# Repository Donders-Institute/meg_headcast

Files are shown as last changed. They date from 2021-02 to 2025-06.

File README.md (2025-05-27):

# Making and using MEG headcasts

Precisely fitting headcasts that fill the gap between the participant's head and the inside of the MEG dewar can ensure that a subject is positioned in the MEG such that he/she cannot move in long experiments, and that the subject can be repositioned in exactly the same way in subsequent sessions. Making a headcast takes time and money.

Relevant literature and links:

- Meyer, Barnes et al. Flexible head-casts for high spatial precision MEG. J Neurosci Methods, 2017. Jan 30;276:38-45. doi: 10.1016/j.jneumeth.2016.11.009
- Chella, Barnes, Pizzella et al. The impact of improved MEG-MRI co-registration on MEG connectivity analysis. Neuroimage. 2019 Aug 15;197:354-367. doi: 10.1016/j.neuroimage.2019.04.061

People with (varying levels of) experience at the DCCN:

- Tom Marshall (currently at Oxford)
- Kristijan Armeni (currently at Johns Hopkins)
- Jan-Mathijs Schoffelen
- Bob Bramson
- Felix Klaassen

## Designing the headcasts

This repository contains code, 3D models, and documentation that was compiled over the years at the Donders Centre for Cognitive Neuroimaging (DCCN) at the Donders Institute, Radboud University Nijmegen, NL.

The [design_v1](design_v1) directory represents the procedure as designed by Robert in 2021. It has been superseded by the [design_v2](design_v2) procedure following the pilots of Bob and Uriel. Please ask Miranda or Jan-Mathijs for up-to-date details.

## 3D printing the head and pouring the foam

In the most recent procedure for pouring the foam we use a 3D printed mold of the dewar that can be disassembled into different pieces. The 3D printed head can be attached to this mold with screws to keep it fixated during the pouring process. The inside of the mold and the outside of the head need to be pre-treated with wax to prevent the foam from sticking too much.

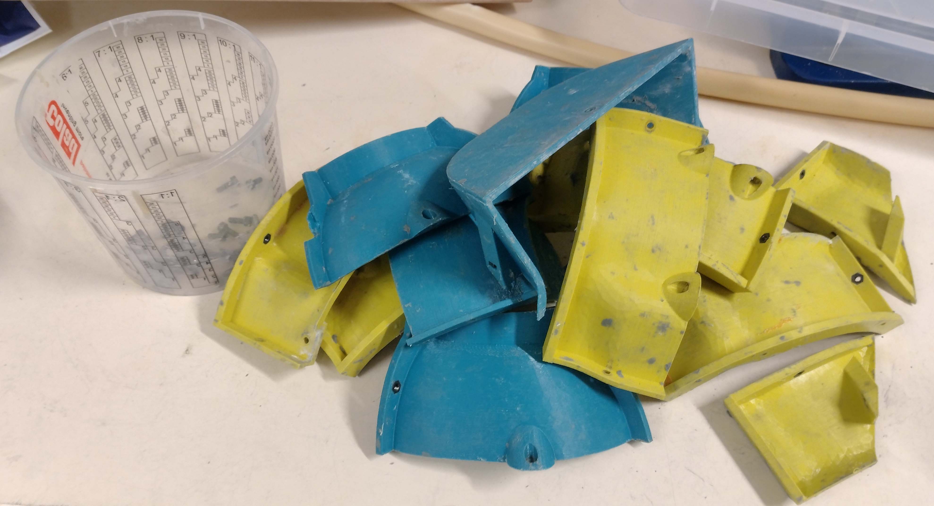
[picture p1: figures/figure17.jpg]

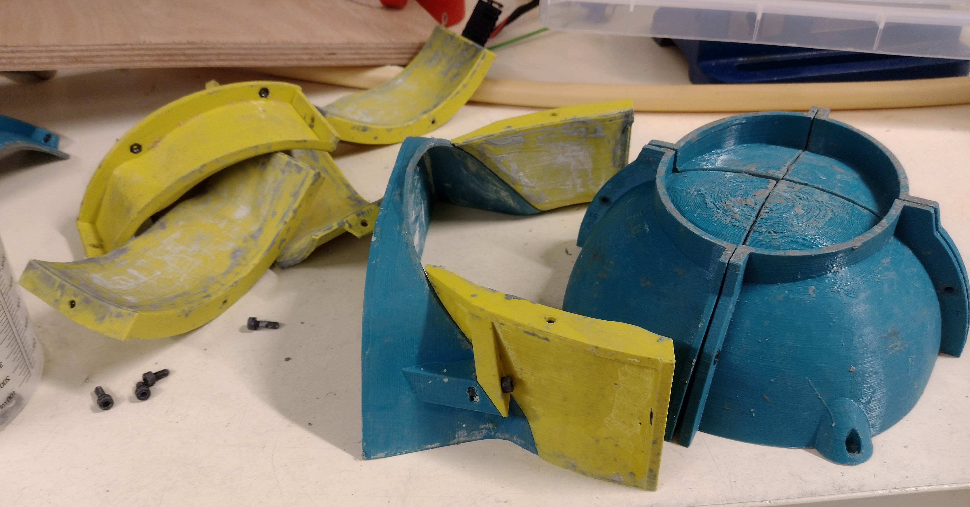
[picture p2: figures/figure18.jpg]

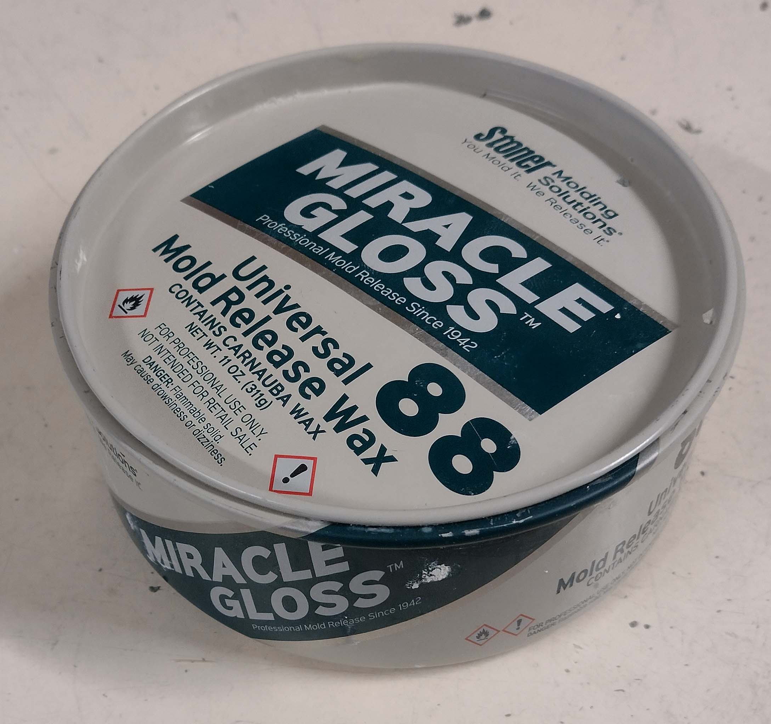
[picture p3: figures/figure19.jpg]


## Safety precautions

We should take extra care with the participants' safety when performing MEG experiments with the headcast in place. Since the participants may be highly immobilized, once positioned, it is very important **NOT** to move the chair! Or to quote Gareth: _"Our primary safety measure is therefore to ensure that neither the chair nor the dewar is moved while the subject is wearing a head-cast"_.

See also <https://www.youtube.com/watch?v=tVozndvAgyw+>

For researchers within the DCCN, please consult the standard operating procedure (SOP), which is included in this repository for reference. When using headcasts in the MEG lab of the DCCN, **always check for the latest version** of the SOP on the [DCCN intranet](https://intranet.donders.ru.nl/index.php?id=meg-lab-procedures).

- [standard operating procedure (DCCN)](labinstructions_dccn/SOP_headcast_20220818.pdf)

Researchers from outside the DCCN might also be interested in the lab procedures that are in use in the MEG lab at the UCL, which Gareth Barnes was so kind to share:

- [standard operating procedure (UCL)](labinstructions_ucl/WTCN_MEG_HEADCAST_SOP_march2015.pdf)
- [emergency procedure](labinstructions_ucl/WTCN_MEG_HEADCAST_Emerg_proc_Appendix2.pdf)
- [training checklist](labinstructions_ucl/WTCN_MEG_HEADCAST_training_Appendix1.pdf)
- [volunteer guide](labinstructions_ucl/volunteerguide_v2.pdf)

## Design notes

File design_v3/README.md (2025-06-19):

# Designing a MEG headcast - iteration 3

This is the 3rd iteration of the process to design and construct individualized headcasts for the CTF MEG system.

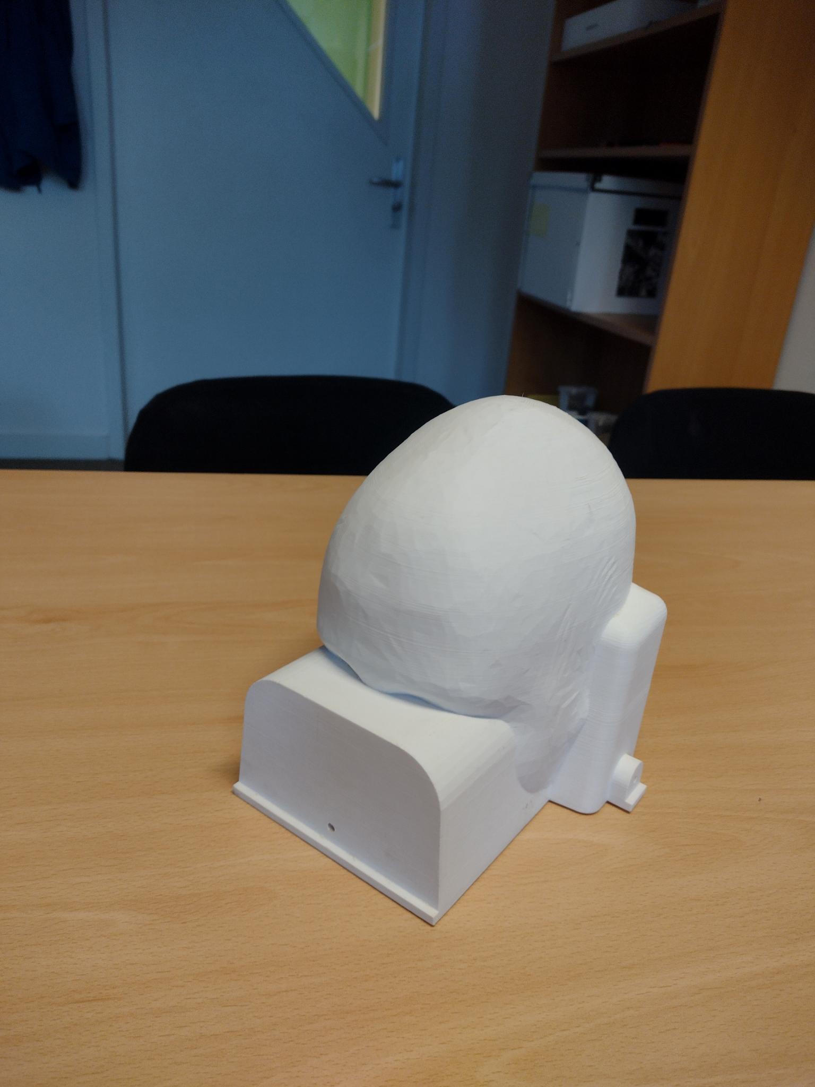
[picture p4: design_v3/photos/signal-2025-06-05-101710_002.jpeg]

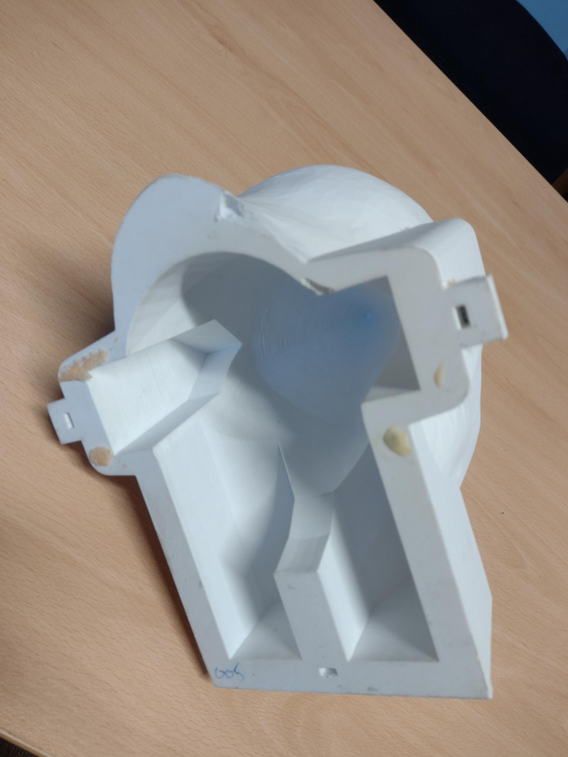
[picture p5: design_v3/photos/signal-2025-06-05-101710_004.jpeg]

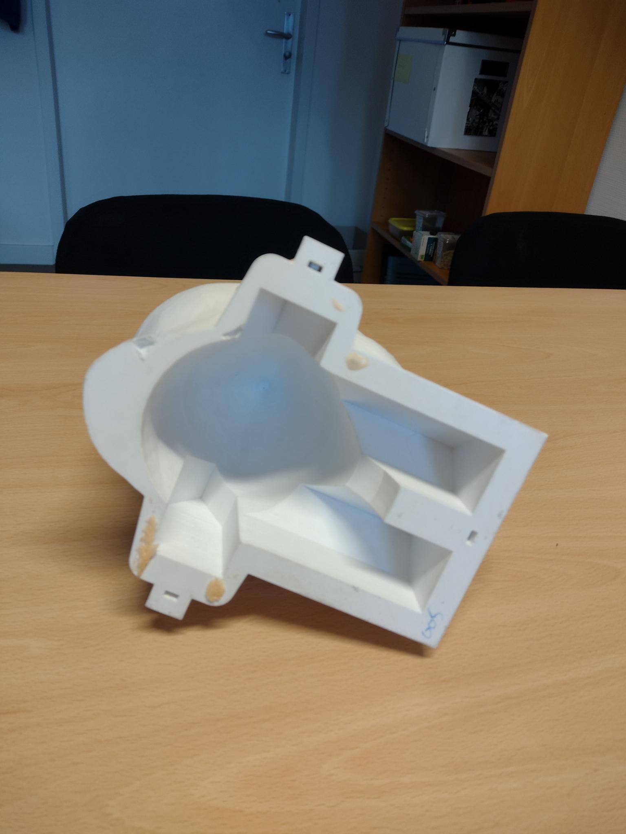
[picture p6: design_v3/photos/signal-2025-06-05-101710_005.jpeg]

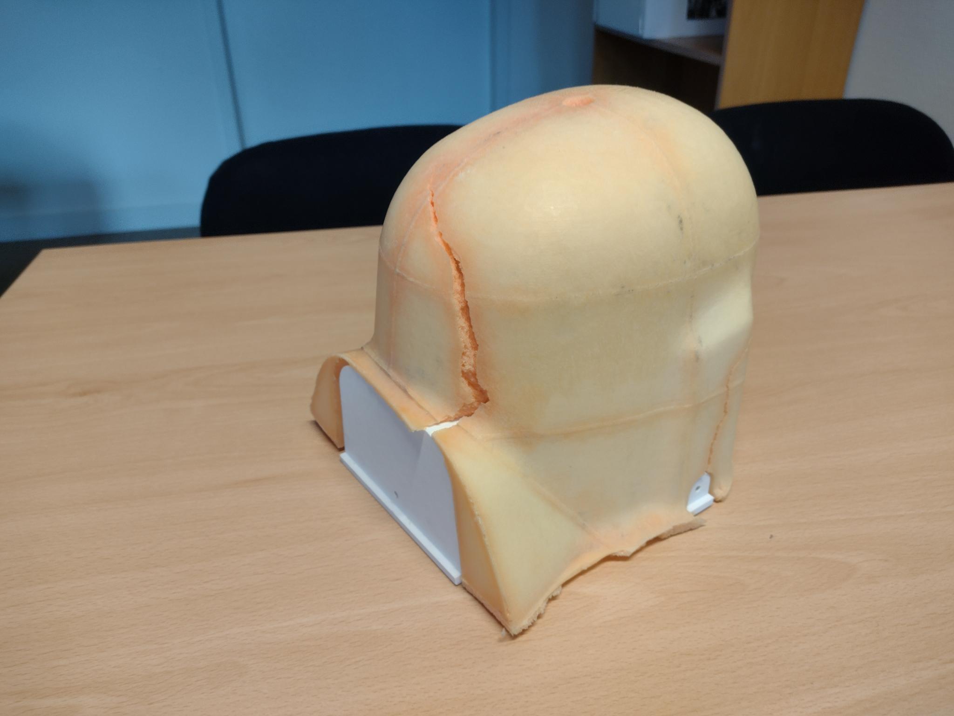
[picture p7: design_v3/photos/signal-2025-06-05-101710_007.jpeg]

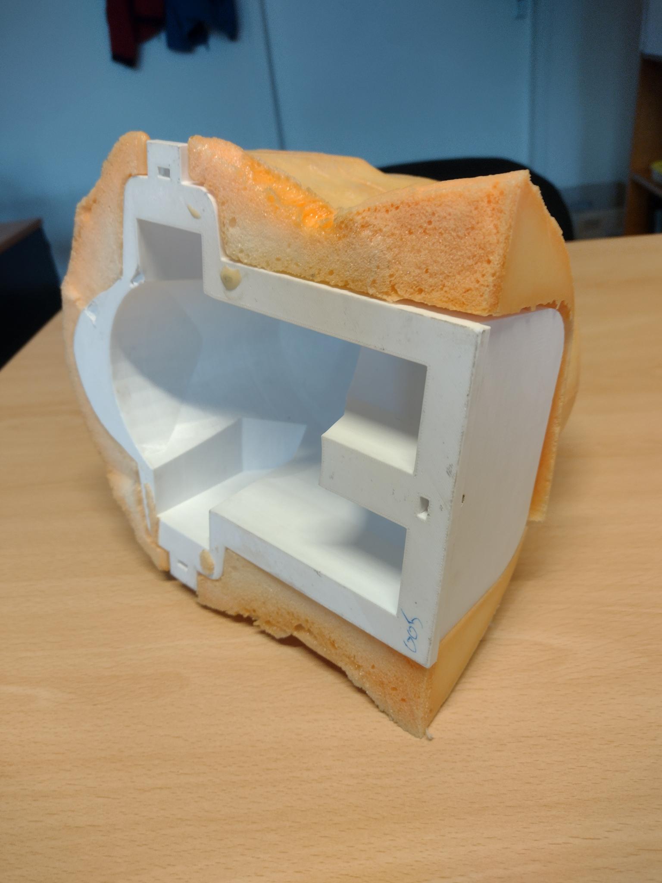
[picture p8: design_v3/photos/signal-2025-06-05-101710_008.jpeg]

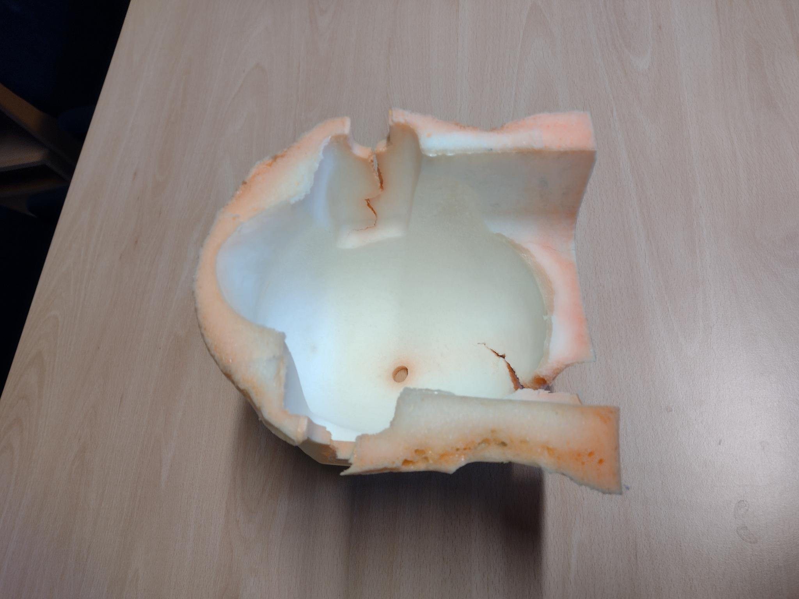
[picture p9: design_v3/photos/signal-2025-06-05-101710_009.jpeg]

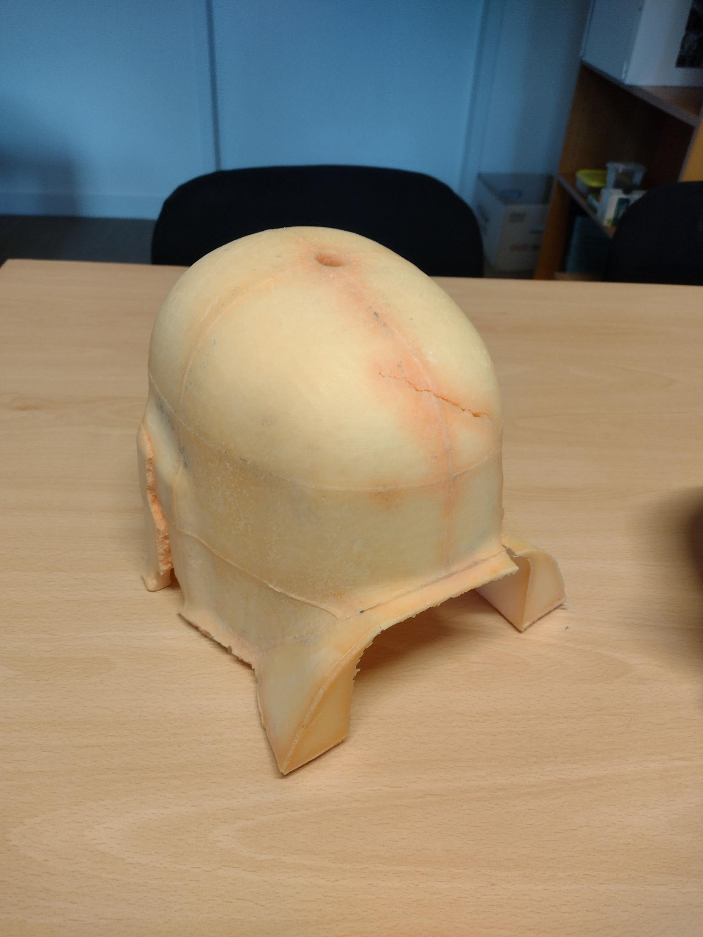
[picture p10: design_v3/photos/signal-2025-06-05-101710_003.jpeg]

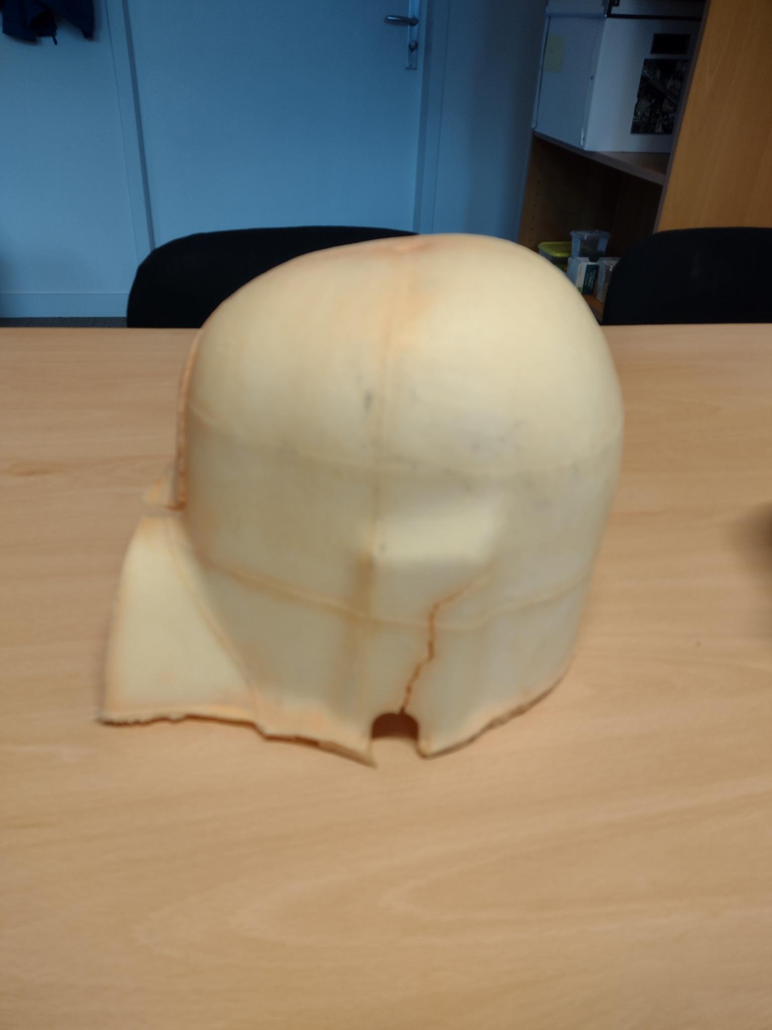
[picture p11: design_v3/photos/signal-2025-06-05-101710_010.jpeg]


We start by making a computer model of the head surface that is aligned properly with the MEG helmet (which is also called the dewar).

First follow the [procedure](./procedure.m) in MATLAB using FieldTrip:

- importing the MRI (as DICOM or NIFTI)
- segmenting the head surface with ft_volumesegment
- positioning the head surface in the dewar using ft_interactiverealign
- exporting the aligned head surface

Then in MeshLab, as explained in this [YouTube video](https://www.youtube.com/watch?v=7c7nLuYW4Ns):

- read in the headshape, neckslab, noseslab, headcore and moldcore STL files.
- subtract the noseslab from the headshape, this removes the tip of the nose (not always needed, but it cannot hurt)
- subtract the neckslab from the headshape, this removes everything below the dewar
- combine the headshape and headcore
- subtract the moldcore from the combined headshape+headcore
- export the resulting mesh as the final STL file to be printed

Printing can be done on any 3D printer with a sufficiently large build volume, but our experience so far has been with a Prusa i3 Mk3 printer and the following settings:

- 0.20 layer height, speed
- Devil Design PETG
- Fill 15%
- No support (*)
- The infill pattern can be 'adaptive cubic' to save, but a regular pattern is also fine.
- 2 or 3 perimeters. More perimeters makes the print stronger, but also increases print time.

(*) If support is needed in the back of the neck, it is recommended  to use organic ssupport, at least if it fits on the base plate. Otherwise, regular support blocks can be used to limit support only to the desired area's.

Pouring of the foam between the 3D printed head model and the piecewise 3D printed model of the dewar is done using the existing procedure, where both the head model and the inside of the dewar model need to be treated with wax to prevent them from sticking to the foam.

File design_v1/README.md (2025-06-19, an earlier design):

# Designing a MEG headcast - iteration 1

This procedure is designed to use [MATLAB](https://nl.mathworks.com/products/matlab.html) and [MeshMixer](https://www.research.autodesk.com/projects/meshmixer/), which is a free software package for 3D design. [MeshLab](https://www.meshlab.net) is another free and useful tool for reviewing and editing STL meshes.

## Summary

The procedure for designing the initial 3D model of the scalp surface and aligning it
with the coordinate system and the head localizer coils is implemented in `do_make_headcast.m`.

To set up the MATLAB path, you can use `do_startup.m`.

The 3D model of the scalp surface is exported to MeshMixer, together with the dewar and a
number of auxiliary shapes (coils, binoculars, earflaps). In MeshMixer these are put together
and the dewar is "subtracted from the scalp model. The resulting model can be 3D printed.

The 3D printed "positive" model is placed in the dewar. Polyurethane foam resin is poured between
the model and the dewar to fill the gap, thereby creating the "negative" head cast.

The `prepare_xxx.m` files are only included for reference, these were used to create
the `.mat` models that are included here.

## Procedure

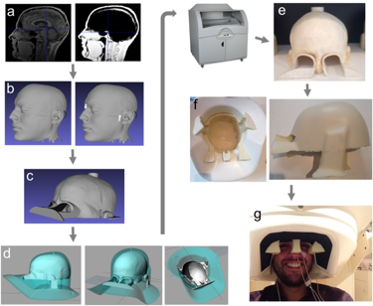
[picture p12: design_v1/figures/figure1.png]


The procedure that is described here can be outlined as follows:

- a) Head surface is extracted from an anatomical MRI image using the standard SPM12 segmentation procedure.
- b) Head surface extraction is converted to a surface file and fiducial coils are added. The coil locations are defined in MRI coordinates.
- c) A positioning cylinder at the top of the head is added to the virtual model to define the position of the head inside the head-cast. Eye extensions are added to enable vision during use.
- d) Using and adjusting the positioning cylinder, eye extensions and ear extensions, the virtual head model is positioned appropriately inside a virtual copy of the MEG dewar.
- e) The positive head model is 3D printed.
- f) The 3D print is placed inside the manufacturer-provided dewar copy (as in d) and foam resin is poured in to fill the gap between the printed positive head model and the dewar. The fiducial coil protrusions on the 3D printed head result in coil-shaped and coil-sized indentations in the head-cast (the nasion coil protrusion is visible between the eyes in e).
- g) The subject can now wear the flexible foam head-cast and enter into the (real) MEG dewar for scanning.

## Making the anatomical MRI

A specific MRI sequence is needed to minimize the distortion at the interface between skin and air. Jan-Mathijs figured out the details with Jose. Our scanners have a sequence according to the FIL specifications, and a better one (according to Jose). Jan-Mathijs compared them with Kris, and they don't appear to differ significantly. In Kris' experiments they used the FIL sequence.

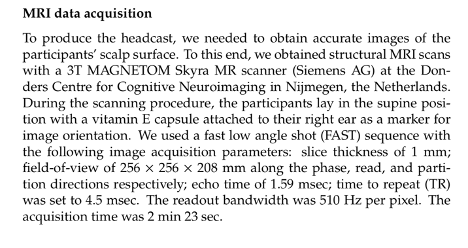
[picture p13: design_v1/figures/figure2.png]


Complete coverage is important, even more so that with a normal anatomical MRI for MEG purposes.

Hair is not visible on the MRI. The ears in the segmented MRI might be too flat to the head, hence the ears need some additional space in the model.

## Creating the 3D model element

The initial MATLAB code from Jan-Mathijs was shared with Bob. I started with the code of Jan-Mathijs, and especially improved on the coregistration and modeling the cut-outs for eyes and ears.

The first phase is implemented in MATLAB and consists of

- importing the DICOM images
- doing a coarse alignment of the MRI to the CTF coordinate system
- segment the head surface
- construct the head surface

The second phase is implemented in MATLAB and consists of

- load the geometrical model of the axes (+x, +y , -y)
- shift the head surface so that it is nicely aligned relative to the axes
- apply the transformation from step 6 also to the anatomical MRI
- export the aligned head surface

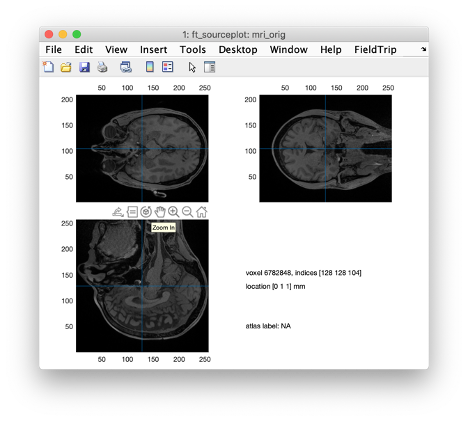
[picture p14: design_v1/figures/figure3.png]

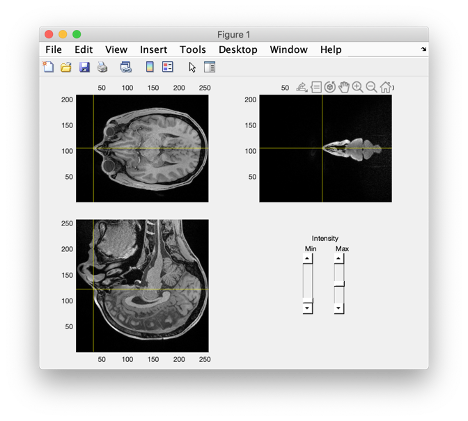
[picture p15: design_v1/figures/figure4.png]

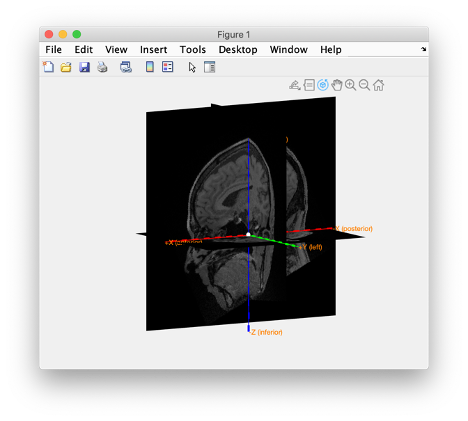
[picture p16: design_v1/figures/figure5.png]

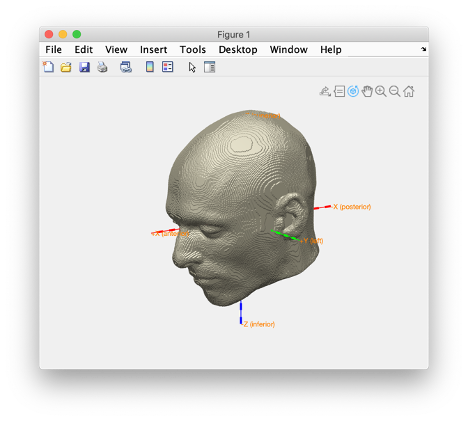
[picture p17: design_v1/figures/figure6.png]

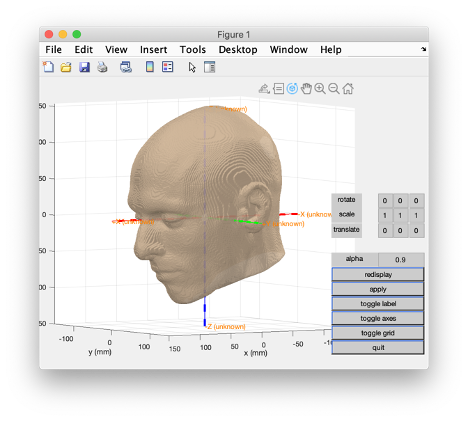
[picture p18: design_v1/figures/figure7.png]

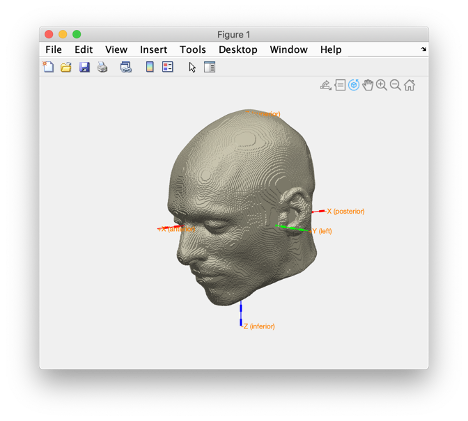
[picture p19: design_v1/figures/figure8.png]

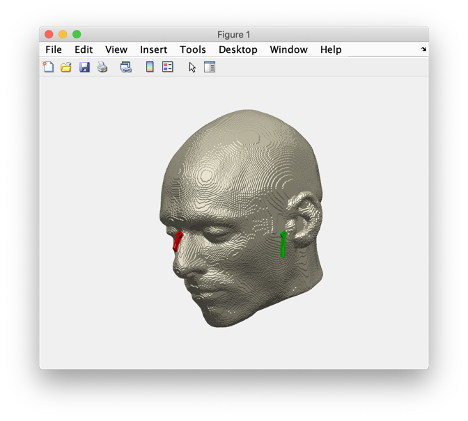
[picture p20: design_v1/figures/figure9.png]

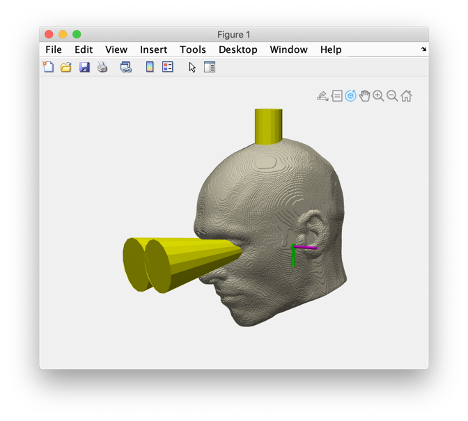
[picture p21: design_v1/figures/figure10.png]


This process results in

- dewar.stl
- earcanal_left.stl
- earcanal_right.stl
- earflap_left.stl
- earflap_right.stl

Which all need to be aligned to the following

- scalp_coreg3.stl
- combined_axes.stl
- headcoil_lpa_coreg3.stl
- headcoil_nas_coreg3.stl
- headcoil_rpa_coreg3.stl
- binoculars.stl
- vertex_cylinder.stl

The scalp and head coils are all aligned to the axes and should not be moved relative to each other, but - if needed - the binoculars and vertex cylinder can be moved for a better fit.

## Positioning the head relative to the helmet (or vice versa)

1. Load all model components in MeshMixer.
2. Check the alignment of the scalp and head coils relative to combined axes, then discard the axes.
3. Hide the ear flaps and canals from view.
4. Move the dewar to the desired position relative to the head.
5. Move the ear flaps to the right position, keep them together (i.e. select them both) when you rotate and translate them, only start moving them separately when you move in and out to have them intersect at the right depth with the head.
6. When you move the ear flaps (together, or separate on left and right), you should keep the ear canals selected as well: you want their surfaces to stay aligned. Only when the flaps are in place, you select the left and right canal and rotate/translate them so that the ear canal spans the whole ear to the top.
7. Optionally: move the binoculars and vertex cylinder.
8. Save the intermediate model to a .mix file.
9. Select the binoculars and cut it with a plane, removing the front of the binoculars. Add a cube, and scale/translate/rotate that so that it forms a slab or a plate to close the front of the dewar. This should prevent the resin from pouring out.
10. Combine the scalp, head coils, ear flaps, ear canals, and front plate in one object. Make that object solid.
11. Select the solid combined model and cut it with a plane, removing everything that sticks out underneath the dewar.
12. Select the dewar and make it solid. Make a copy of it, you will need it later.
13. Select the solid model and the solid dewar, then do boolean difference. Use intersection curves.
14. Select the solid model and do separate shells. This will convert it into multiple objects. Keep the large part that is inside the dewar and delete all other small marts (e.g. the top part of the cylinder that sticks out, and the outer parts of the ear flaps).
15. Save the final model to another .mix file.
16. Export the solid model to an STL file, note: do not press Ctrl-S but do “save as” to prevent overwriting the intermediate model, you may want to return to that model.
17. Optionally export the copy of the solid dewar, this will help in later visualisation

Tilt the neck so that the subject is in a comfortable position. At this moment it is also important to think of the position of the head in the dewar; some studies might have more interest in the frontal parts of the brain, or in the occipital parts, and hence might want to try to get those specifically closer to the helmet.

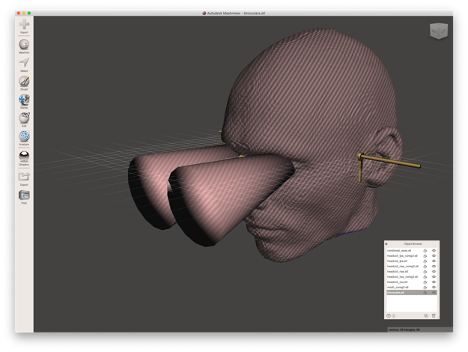
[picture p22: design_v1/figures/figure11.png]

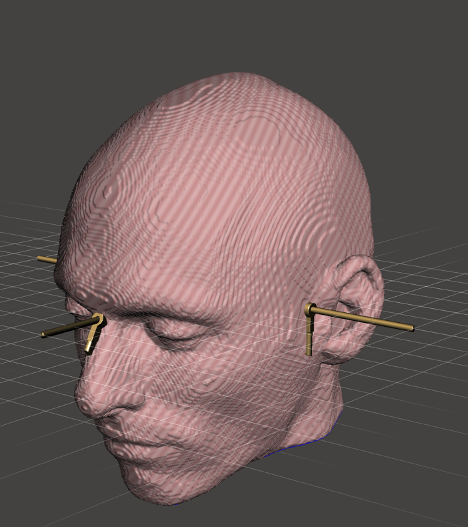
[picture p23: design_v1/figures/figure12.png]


The third phase is implemented in MeshMixer and consists of

- load the geometrical model of the aligned head surface
- load the geometrical model of the axes (+x, +y , -y)
- load the geometrical model of the LPA, RPA and NAS head localizer coils
- move the head localizer coils along the axes to the scalp surface
- load the geometrical model of the "binoculars"
- if needed move the binoculars to match the subjects eye position and gaze direction
- load the geometrical model of the vertex cylinder
- if needed move the vertex cylinder
- remove the geometrical model of the axes
- merge the head surface, coils, cylinder and binoculars in a single surface
- load the model of the dewar
- move the dewar so that the head is properly positioned, paying attention to the gaze direction
- crop the aggregate head model to remove everything that is outside the dewar
- crop the aggregate head model to remove the neck and lower head

The fourth phase is implemented in MeshMixer and consists of

- make the aggregate head model hollow
- export the aggregate head model to an STL file to get it printed

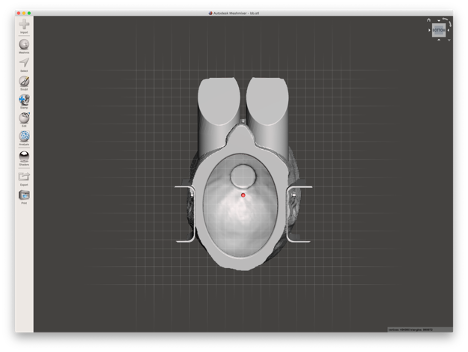
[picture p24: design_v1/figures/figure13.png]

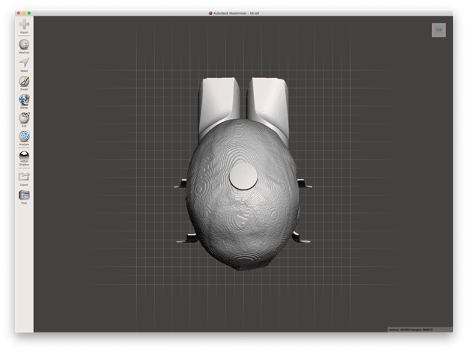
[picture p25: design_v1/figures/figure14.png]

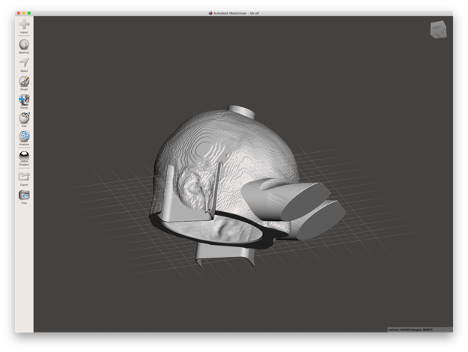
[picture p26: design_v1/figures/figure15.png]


After the 3D model has been written to STL format, it can be sliced and printed. Printing can done with FDM (Fused Deposition Modeling) using a filament, or using SLS with a powder and a laser.

The first model I finished fits on the print bed of a Prusa i3 mk2s printer, see screenshot. Estimated printing time is approximately 69 hours, requires appropriately 250 meter filament (including all supports), which costs about 15 euro.

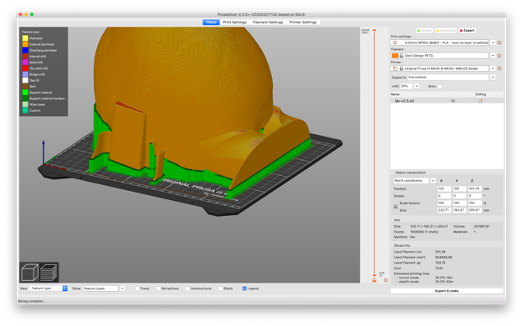
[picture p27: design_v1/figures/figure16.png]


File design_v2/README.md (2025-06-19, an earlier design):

# Coregistering a MEG headcast - iteration 2

The code and models in this folder have been written with the purpose of doing coregistration, not
so much for creating the model that is is to be 3D printed.

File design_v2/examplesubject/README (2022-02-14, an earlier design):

This directory contains for pil-002 the anatomical image that
was used to create a few headshape_*.stl files. From one of those
headshapes, the pil-002_*.stl files were derived. The latter files
reflect the location of the head localizer coils on the printed
headsurface, as well as the placement of the headsurface in the dewar
helmet. In combination with the *.ds dataset, which was obtained with the
headcast in place, it should be possible to obtain a mapping between the
sensors and the dewar helmet surface. 

The *.ds dataset is a mvDs result of the original 01_Headlocalization_20220211_01.ds
dataset, that is in the catch all collection. The identity of pil-002 is
Jan-Mathijs Schoffelen. 

CONTEXT:

Based on interactions with the CTF-engineers, it's likely that the
inaccuracy of the alignment between sensors and dewar helmet is not to be
neglected. In other words, alignment of headcast with the MEG based on
geometrical information might not be sufficiently accurate. Geometry based
alignment is assumed to be possible in the context of headcasts that do not 
explicitly include spare room for the head localization coils. The first
generation headcasts created in London (e.g. pil-002) include the coils.
The headcasts created with the DCCN protocol do not include the coils.
This makes the latter amenable to coregistration inaccuracies introduced
by the researcher (e.g. in the Polhemus procedure, or by coregistering
the anatomical image). On the other hand, placing the coils on the
subject directly, rather than in the cast, gives a more accurate account
of the residual movement during the MEG measurement.

The engineers at CTF claim the head localizer coil base coregistration
might be more accurate than the geometrical details they have provided
about the sensors-in-dewar configuration. The idea would be that pil-002 
is to be used as a 'benchmark' subject to do a head localizer based
coregistration. As long as the system geometry is stable i.e. in between
maintenance sessions during the which the sensors are taken out, it is
probably the best estimate that can be made.

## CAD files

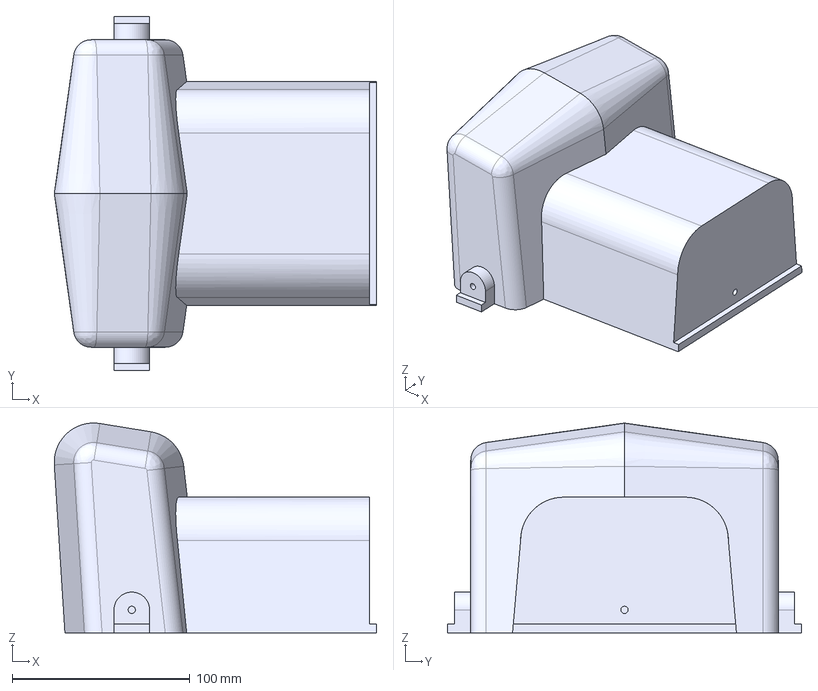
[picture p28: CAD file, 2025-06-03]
design_v3/models/step/headcore.step
181.4 x 199.1 x 118.1 mm

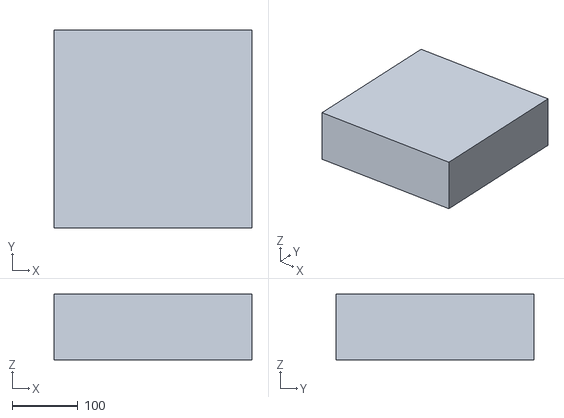
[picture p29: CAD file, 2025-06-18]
design_v3/models/stl/neckslab.stl
300.0 x 300.0 x 100.0

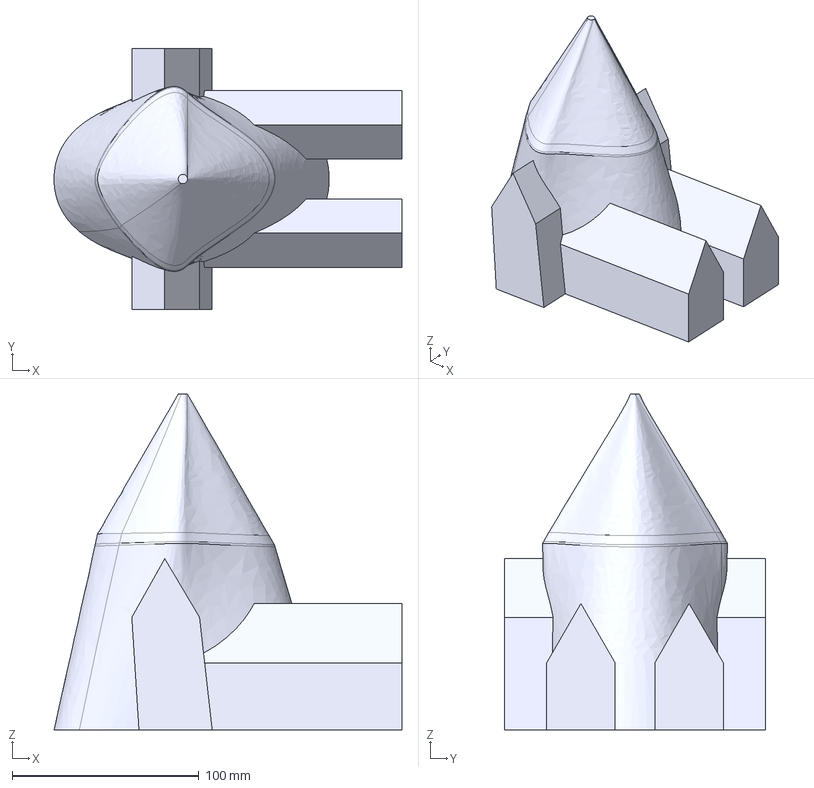
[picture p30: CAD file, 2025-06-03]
design_v3/models/step/moldcore.step
186.6 x 140.0 x 180.0 mm

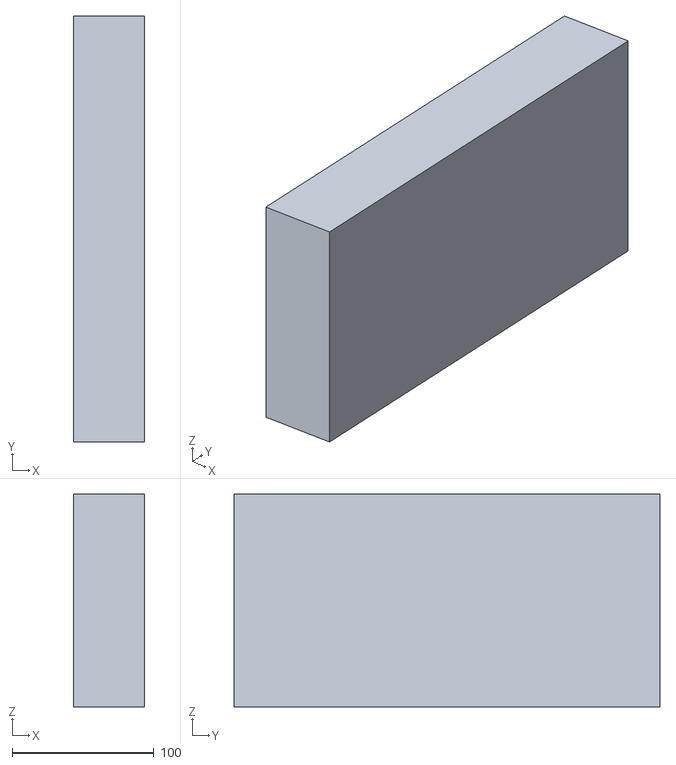
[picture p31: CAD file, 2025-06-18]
design_v3/models/stl/noseslab.stl
50.0 x 300.0 x 150.0

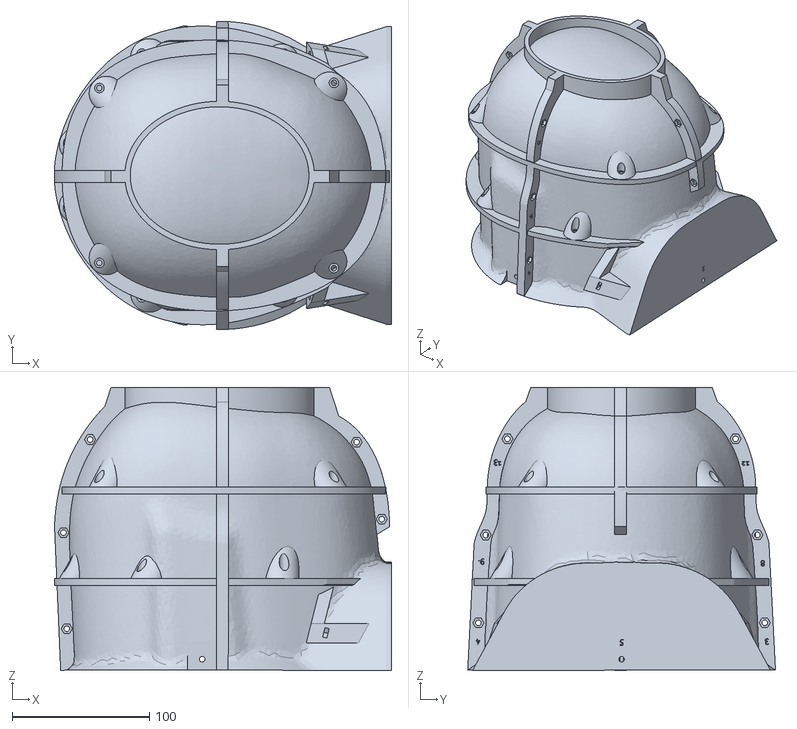
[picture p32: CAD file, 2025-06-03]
design_v3/models/stl/dewar.stl
245.3 x 224.2 x 206.0

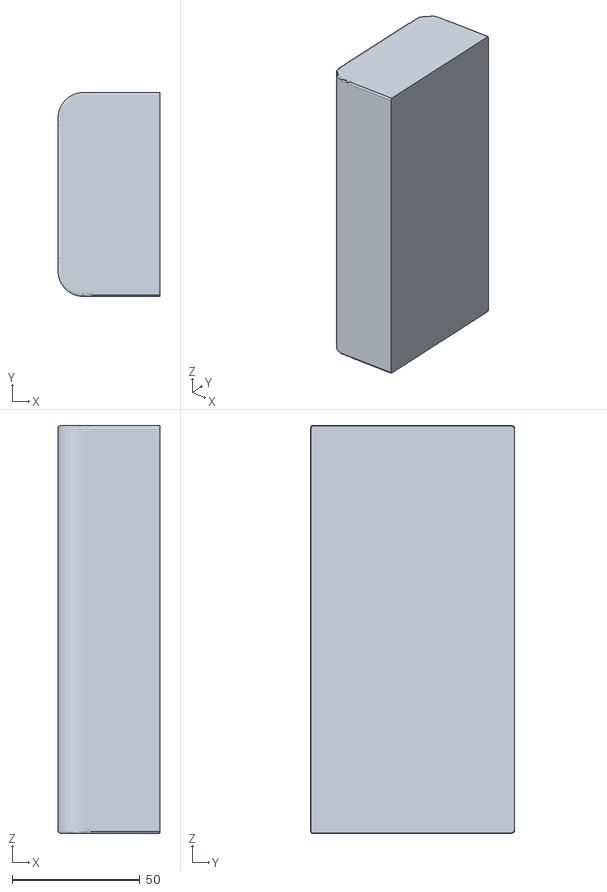
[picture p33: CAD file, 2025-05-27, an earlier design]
design_v1/models/stl/earflap_solid.stl
40.0 x 80.0 x 160.0

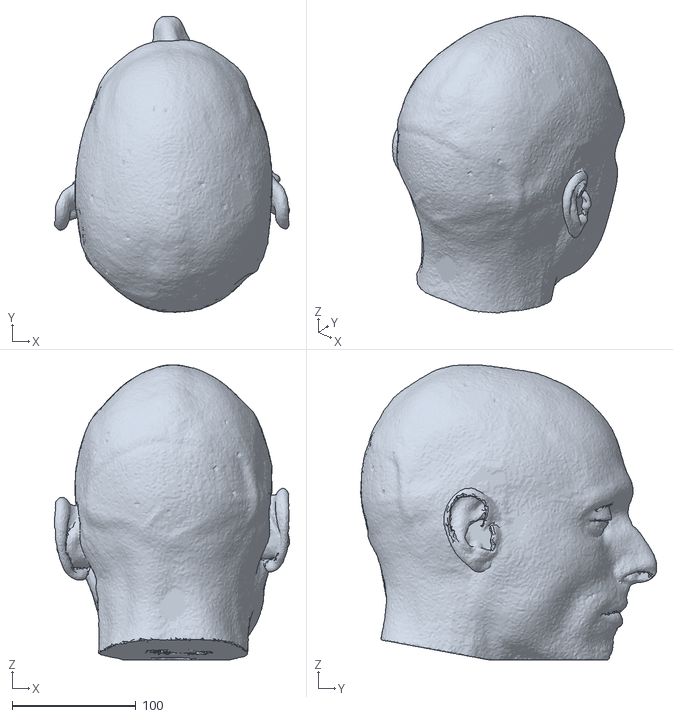
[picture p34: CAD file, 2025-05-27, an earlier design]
design_v2/examplesubject/headshape_iso2mesh_ups.stl
190.0 x 239.5 x 238.5

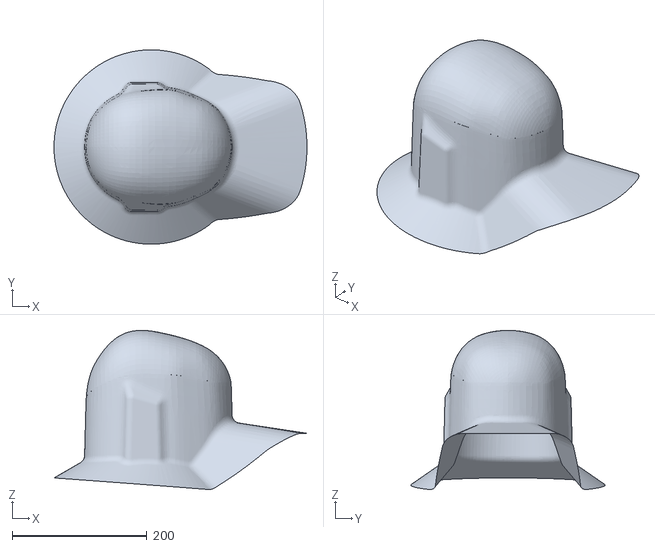
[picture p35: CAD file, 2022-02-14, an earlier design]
design_v2/models/stl/dewar_ctf.stl
375.2 x 288.2 x 236.2

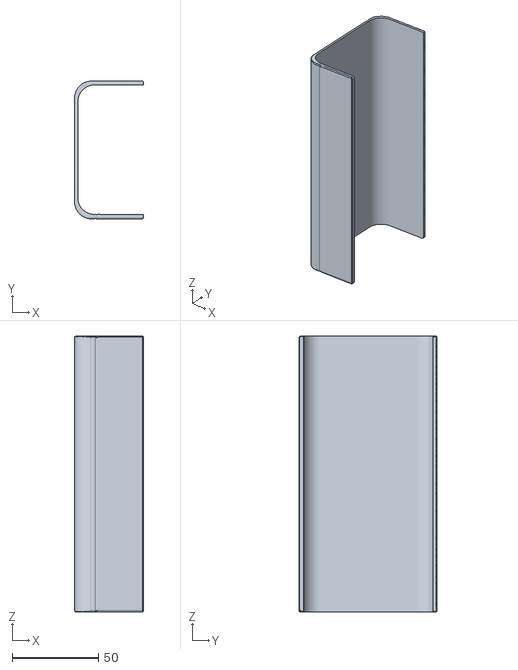
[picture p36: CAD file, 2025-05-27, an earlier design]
design_v1/models/stl/earflap_hollow.stl
40.0 x 80.0 x 160.0

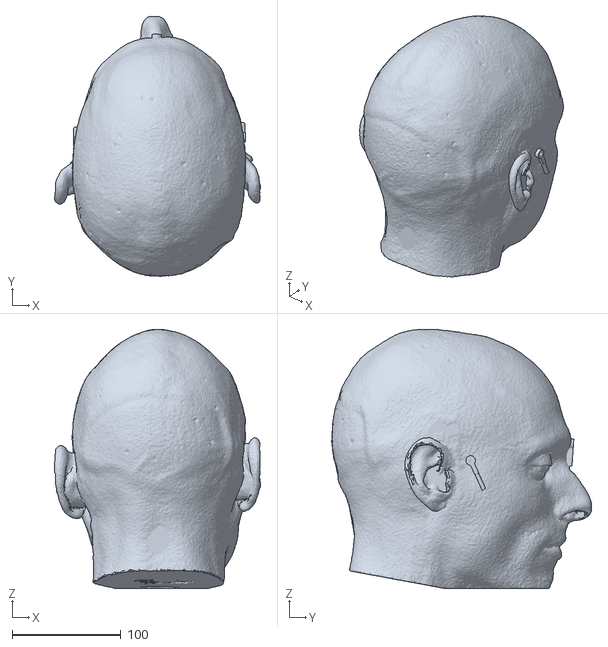
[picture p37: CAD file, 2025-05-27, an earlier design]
design_v2/examplesubject/pil-002_fiducials.stl
190.0 x 239.5 x 238.5

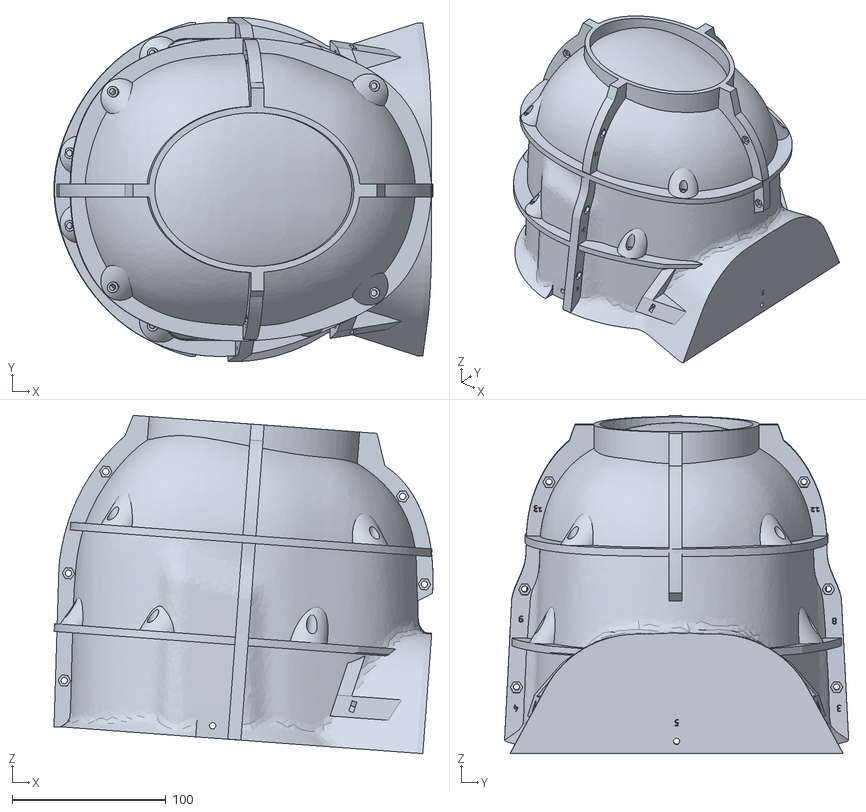
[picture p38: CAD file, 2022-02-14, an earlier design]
design_v2/models/stl/dewar_mold.stl
246.8 x 224.2 x 220.3

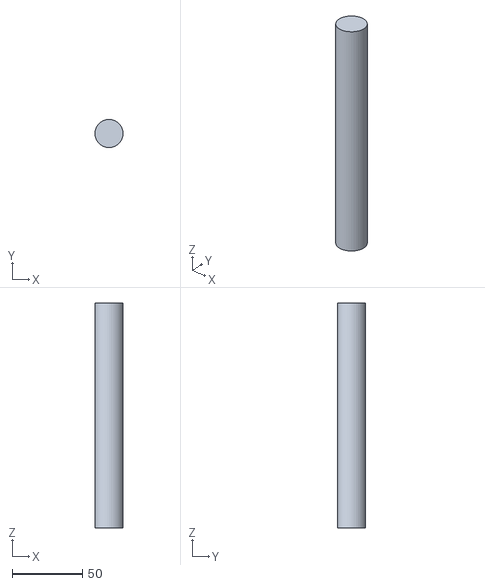
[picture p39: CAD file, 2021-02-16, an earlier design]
design_v1/models/stl/earflap_part1.stl
20.0 x 20.0 x 160.0

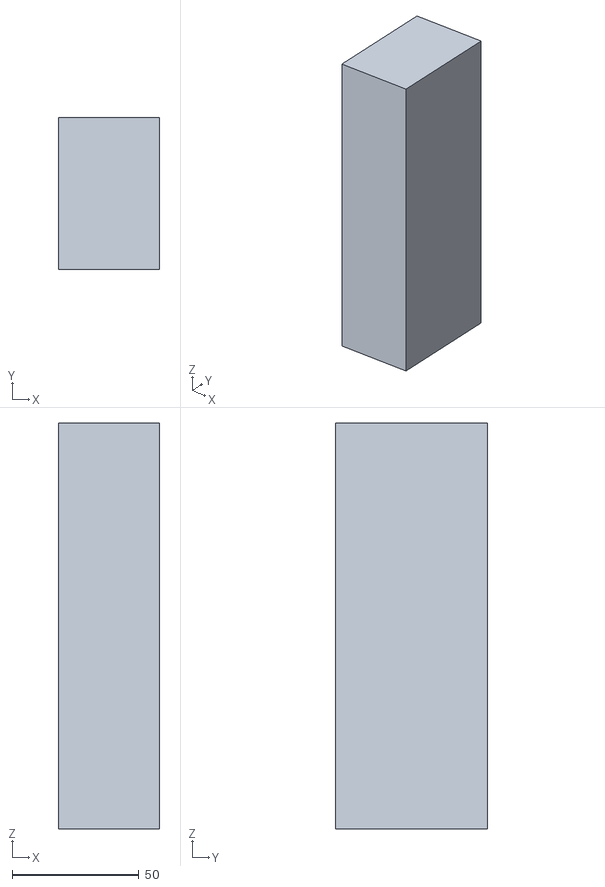
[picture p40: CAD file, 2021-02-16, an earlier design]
design_v1/models/stl/earflap_part3.stl
40.0 x 60.0 x 160.0

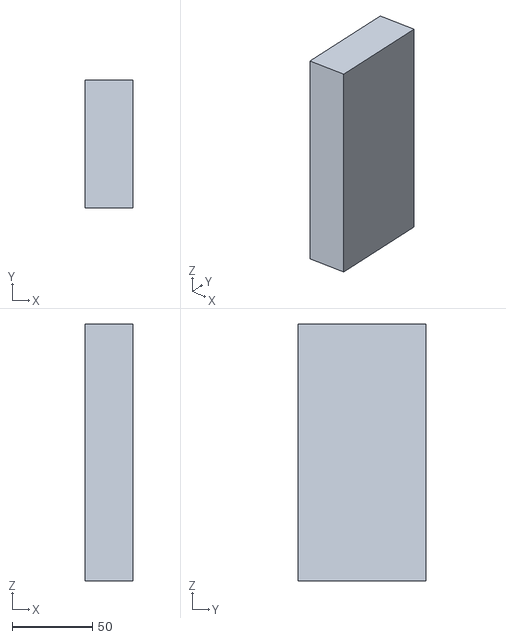
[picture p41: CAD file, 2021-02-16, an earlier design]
design_v1/models/stl/earflap_part4.stl
30.0 x 80.0 x 160.0

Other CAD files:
design_v2/examplesubject/headshape_iso2mesh.stl
design_v1/models/stl/earflap_part2.stl
design_v1/models/stl/headcoil_lpa.stl
design_v1/models/stl/headcoil_nas.stl
design_v1/models/stl/headcoil_rpa.stl
design_v3/models/stl/headcore.stl
design_v3/models/stl/moldcore.stl

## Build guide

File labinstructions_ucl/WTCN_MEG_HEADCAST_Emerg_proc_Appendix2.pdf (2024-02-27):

Appendix II: Head-cast emergency procedures

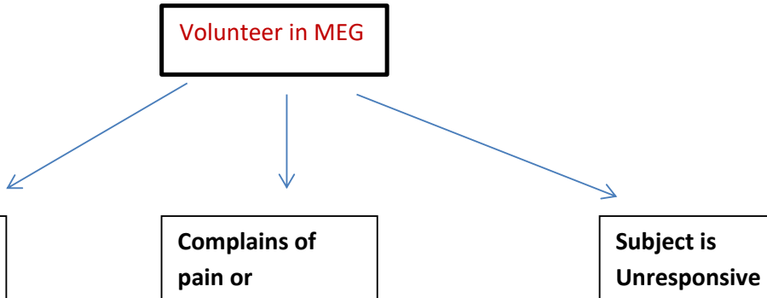
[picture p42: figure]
Volunteer in MEG; Complains of pain or; Subject is Unresponsive
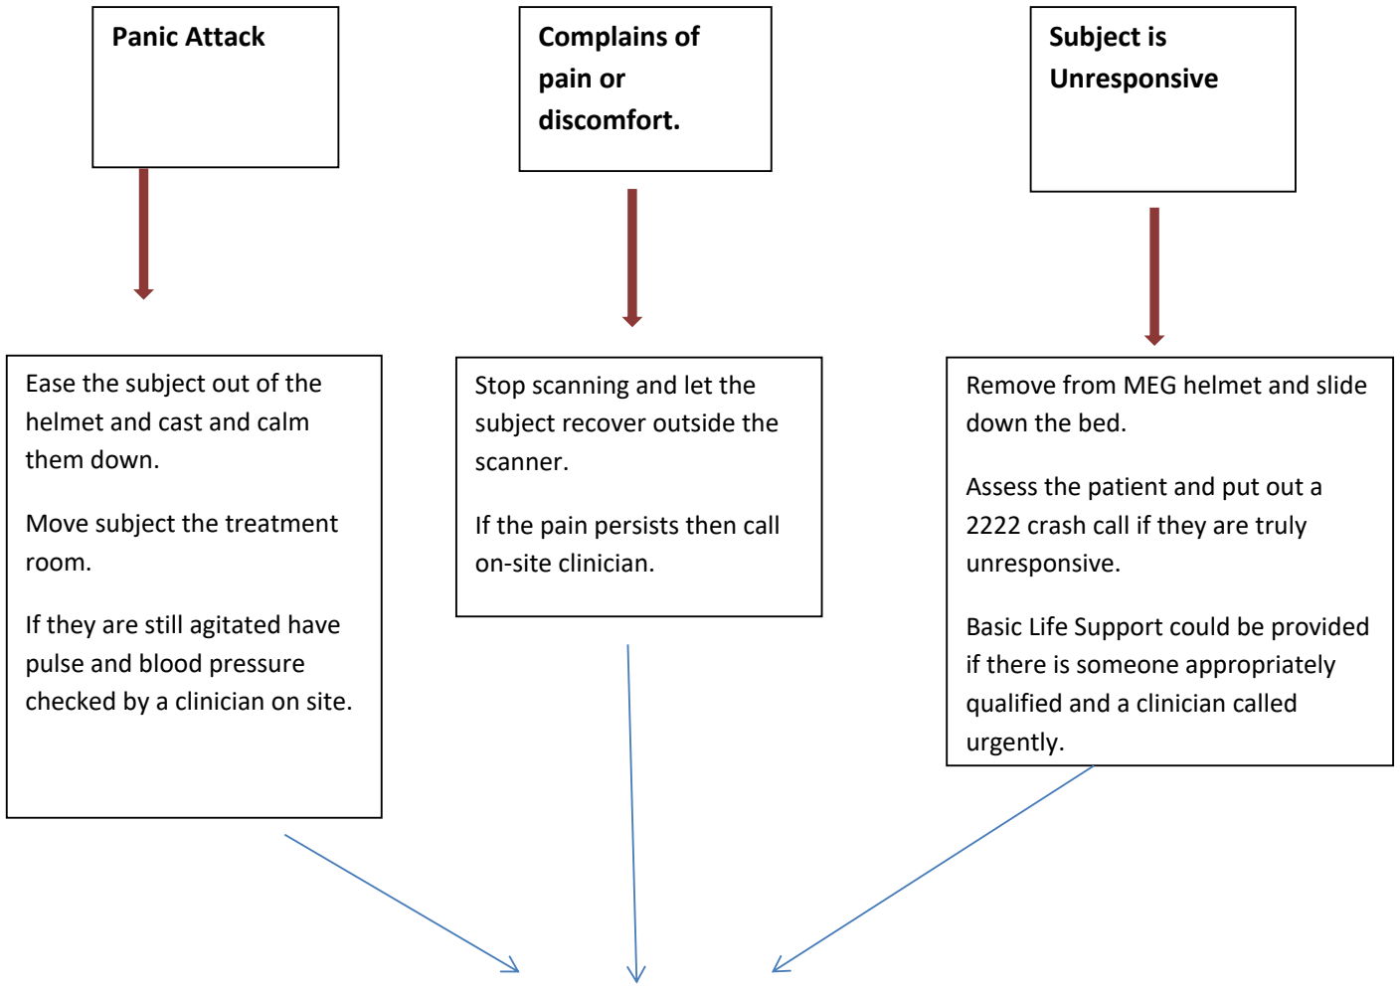
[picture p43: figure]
discomfort.; Panic Attack; Remove from MEG helmet and slide down the bed.; Assess the patient and put out a 2222 crash call if they are truly unresponsive.; Basic Life Support could be provided if there is someone appropriately qualified and a clinician called urgently.; Stop scanning and let the subject recover outside the scanner.; If the pain persists then call on-site clinician.; Ease the subject out of the helmet and cast and calm them down.; Move subject the treatment room.; If they are still agitated have pulse and blood pressure checked by a clinician on site.

MEG_ HEADCAST_EmergProc_Nov2014

## Emergency Head cast procedures :

Press the panic alarm button to get help. Call for a clinician within the building.

ONLY Authorised personnel are allowed to scan volunteers with a head-cast.

Debrief subject and send report to

sofie.meyer.10@ucl.ac.uk

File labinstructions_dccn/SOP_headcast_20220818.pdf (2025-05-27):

Version 1.2 18-08-2022

## Standard Operating Procedure – using MEG head casts

PURPOSE:
In order to ensure the safety and comfort of participants scanned while wearing head casts, the outlined procedures are to be followed by all researchers for all MEG scans involving head casts. The aim is for negligible risk and minimal burden to subjects by proper training and instruction.

SAFETY:
The head cast is designed to fit the subject’s head internally and the MEG dewar externally. This means that the participant’s head will be reasonably fixed inside the dewar and any unexpected movement of the participant has the potential to cause injury. To summarize this document:

NEVER MOVE THE MEG CHAIR OR DEWAR WITH THE PARTICIPANT’S HEAD IN THE MEG WHILE WEARING A HEAD CAST

RESPONSIBILITIES:

- Researchers must be MEG and head cast certified user before applying the MEG head cast procedure on a subject.
- The DCCN Principle Investigator of the study ensures that the researcher is a MEG and head cast certified user before starting subject inclusion.
- The MEG lab manager is responsible for head cast training, certification and keeping the content of the documentation up-to-date.

KEY WARNINGS:

- The dewar and chair (i.e. all moving parts) should remain locked in position whenever the subject is wearing the head-cast. This will minimize risk of neck injury.
- The chair should be positioned directly against the gantry.
- The head casts should only be used with healthy volunteer subjects. The researcher must have done two sessions without problems during prime time before the head casts may be used outside of prime time hours. Outside of prime time hours a buddy must be present.
- The head casts should only be used while subject is seated – The use of the head cast in supine position is only allowed if there is an extra support system to keep the bed in place.

GENERAL PROCEDURES:

1. Only certified MEG users who have completed the head cast specific safety training are certified to handle subjects during MEG scans involving head casts.
2. Subjects must be informed about the use of MEG head casts prior to their visit.
3. Prior to inclusion and head cast construction, subjects must be informed about the use of the head cast and, on their first visit, introduced to the procedures using the MEG dewar and head cast model.
4. Before the participant is placed in the MEG, the MEG dewar dummy model is used to practice going in and out of the scanner. If the participant is not able to easily come out of the MEG dewar model the experiment stops there and the scanning will not take place.
5. As usual, all study participants will be explicitly informed that they can withdraw from participation at any time without further explanation.

EXTRA OPERATION STEPS FOR A MEG HEAD CAST EXPERIMENT:

Subject Preparation (Initial Session):

- MRI Scan
- Subject is informed about the MEG and head cast procedure

Subject Preparation in control room:

- The researcher checks if there is a hole in the top of the head cast. The hole in the head cast is there to prevent a vacuum effect.
- Talcum powder will be placed on the exterior of the head cast to minimize friction with the interior of the dewar.
- Properly instruct subject how to put on the head cast outside of the scanner.
- Allow subject to wear the head cast outside of the scanner for proper fit.
- If the head cast is too tight the head cast can be adjusted under supervision of the TG. There is a special toolbox for this in the office of Uriel.
- Subject must practice exiting the dewar dummy model by pressing in and pulling down the head cast earflaps.
- If the subject is not able to exit the head cast by themselves the experiment stops there.
- Explain how the subject has to enter and exit the dewar while wearing a head cast.
- Provide opportunity for questions & any concerns before continuing.
- Subject maintains right to withdraw participation at any time without further explanation

Subject Preparation in MSR:

### 1. Without head cast on:

- Chair is at the lowest position
- Lock all seat operation valves
- Have the participant seated
- Unlock the seat raise valve
- Raise the seat until the participants head touches the dewar
- Lock the seat raise valve
- The participant “crawls” out of the seat
2. The participant puts on his head cast – when the head cast is on all moving parts must be locked

### 3. With the head cast on:

- The participant slides back in the seat and puts his head back in the dewar
- If the seat height needs adjustment, see procedure 4
- Practice sliding in and out the dewar
- If the subject is not able to exit the dewar by themselves the experiment stops there
- Slide out of the dewar
- Place head localization coils
- Put head back in the dewar
- The shielded room will be sealed
- Researcher must always see and hear the subject
- The experiment can now begin

### 4. If the seat height needs adjustment:

- the participant “crawls” out of the seat,
- Participant gets back in the seat without head cast
- Unlock the seat raise or seat lower valve
- Adjust the height
- Lock the seat raise or lower valve
- Participant “crawls” out of the seat
- Participant puts on the head cast
- Participant gets back in the seat and puts head in the dewar

Appendix: Head Cast Safety Training Checklist

In addition to the standard MEG certified user checklist, the following are important:

ð | Researcher has completed standard MEG certified user checklist
ð | Researcher has read/understood the MEG Head Casts Standard Operating Procedure (SOP)
ð | Researcher has demonstrated they can competently follow the head cast SOP & understands
| the key dangers
ð | Researcher is familiar with all subject monitoring equipment (i.e. video & audio) & signs the
| log-book with the understanding that this signifies all monitoring was maintained throughout
| experiment
ð | Researcher is familiar with emergency procedures (emergency contact numbers)
ð | Researcher is aware of how to screen subjects for head casts (when to use, if unsure DO NOT
| continue)
ð | Researcher has demonstrated ability to fit a participant’s head cast outside of the scanner
| using the dewar template & can competently instruct a subject in all experimental
| procedures
ð | Researcher understands when to stop the experiment

## Change log

Version 1.2

- Head casts can be used in supine position if extra support system for the bed is used.

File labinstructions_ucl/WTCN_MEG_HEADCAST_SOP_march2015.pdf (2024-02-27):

Head-Cast SOP. 20/11/2014

1

### Standard Operating Procedure for use of flexible head-casts in MEG

Title: | Appropriate procedures and practices for use of flexible head-casts in MEG | Document source: | MEG Community website
SOP Version: | 1 | Last edited date: | 19/11/2014
Prepared by: | Sofie Meyer and Benjamin Hunt | Approved by: | Gareth Barnes

General safety:

The flexible head-cast is designed to fit the subject’s head internally and the MEG dewar externally. This means that the participant’s head will be firmly fixed inside the dewar and any unexpected movement of the chair or MEG system has the potential to cause injury. To summarise this document:

NEVER MOVE THE MEG CHAIR OR DEWAR IF THE HEAD-CAST IS ON THE SUBJECT’S HEAD.

Purpose:

In order to ensure the comfort and safety of participants scanned while wearing head-casts, the outlined procedures are to be followed by all researchers for all MEG scans involving head-casts. If any additional concerns arise that would be appropriate to include here please send detailed descriptions to sofie.meyer.10@ucl.ac.uk for inclusion to future versions of this document.

Responsibilities:

Researcher(s): To complete the head-cast specific safety training and to know and follow the safety procedures described in this SOP. For the WTCN training programme, see Appendix I. Chief Investigator: To ensure that all researchers have completed the head-cast specific safety training and that at least two researchers are present during scanning which only takes place during normal working hours when clinicians and support staff are on site.

Key warnings:

The dewar and chair (i.e. all moving parts) should remain locked in position whenever the subject is wearing the head-cast. This will minimize risk of neck damage.

The head-casts should only be used with healthy volunteer subjects and during normal hours.

The head-casts should only be used while subject is seated – never use in supine position.

Some subjects may find the head-localisation coils create pressure which could cause headache.

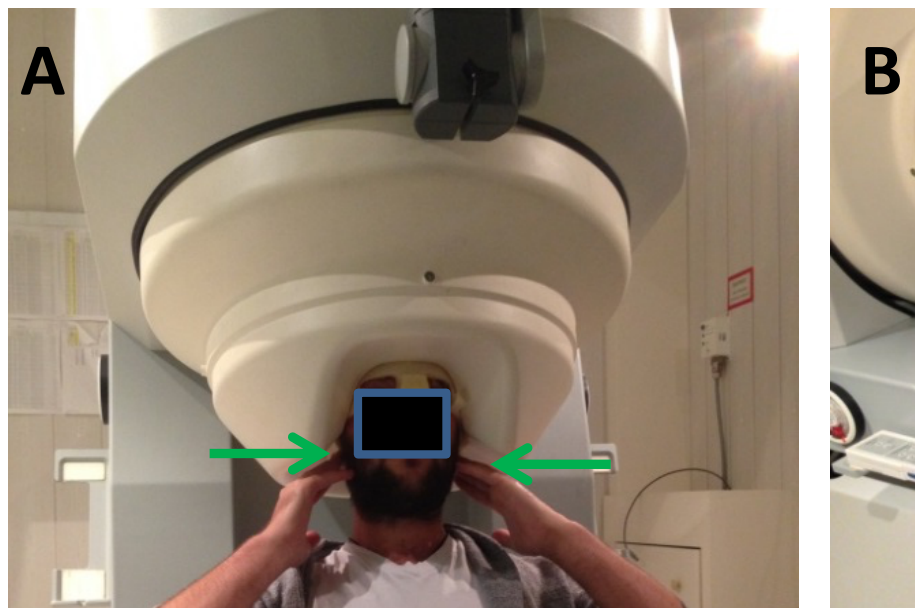
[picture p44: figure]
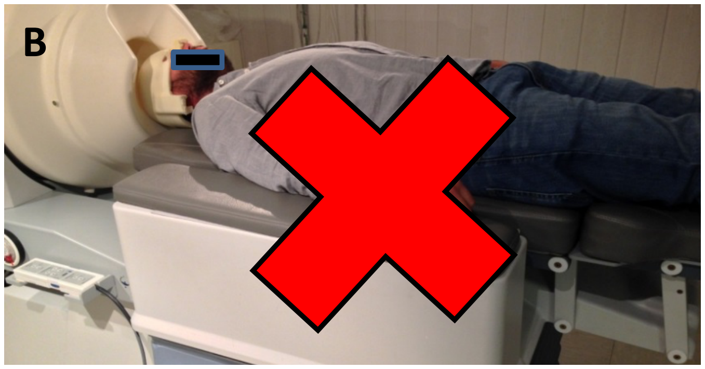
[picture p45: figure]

Fig. 2: A. To exit, press ear flaps inwards to reduce contact surface area between dewar and head-cast and slide out. B. Never use the head-cast in supine position. Subject is helpless if the bed is moved and

Head-Cast SOP. 20/11/2014

2

Date:_________________ Subject ID: _________________ Log book number: ______________

Researchers present: ________________________&___________________________

Researcher preparation:
Researchers must know where the panic alarm for the room is located and what the relevant emergency phone numbers are.
At least one researcher must be an MEG qualified user and head-cast safety trained while the other must, at minimum, be familiar with the safety documents and scanning procedure.
On the subject’s first visit, and generally recommended in case of panic attack / claustrophobia, confirm number and name of a clinician in the building _________________________. Subject preparation (outside the scanner):
Inform participant that they have the right to stop the scan at any time if they are uncomfortable with the equipment, procedure, or paradigm.
Obtain written consent from participant.
Confirm that the subject does not have any allergies to polyurethane foam products.
Demonstrate how to put on the head-cast outside of the scanner.
Allow participant to try wearing the head-cast outside of the scanner and ensure that it is comfortable. Cut out potential pressure points if needed.
Fit the portable dewar template over the head-cast to give the participant an idea of what the head-cast will feel like within the scanner.
Use talcum powder to minimize friction between the head-cast and interior of the dewar. Apply to surface of the head-cast (and re-apply during scanning breaks). To protect the participant’s clothes from this, a gown is recommended.
Participants should practice pressing in on the head-cast earflaps to exit the dewar template. Explain how the participant will sit in the scanning chair and be raised vertically into the dewar. Give participant the opportunity to ask any questions and raise any concerns before entering the shielded room.
Verify that the subject does not display an allergic reaction to the head-cast.
Positioning the subject in the scanner (without the head-cast)
Move chair to lowest level.
Lock controls so chair cannot move forward or backward.
Lock controls so chair back/seat angle cannot change.
The chair must have a sheet or blanket to allow the participant to glide out of the chair.
Elevate chair for normal MEG scanning. i.e. the top of the subject’s head (without head-cast) is just touching the inside of the dewar.
Lock chair in position. Now all moving parts should be locked in position for the duration of the experiment.
Let the subject practise sliding in and out of dewar (without head-cast).
Show participant the squeeze bulb or panic button and demonstrate sound before the scan. Positioning subject in scanner with head-cast:
Ensure that chair and all moving MEG system parts are locked in position.
Now allow the subject to slide themselves into dewar wearing the head-cast.
The participant should then practice exiting the dewar using the ear-flap method (figure 2A) before the experiment starts.
Scanning:
Place MEG coils in the head-cast indentations.
Participant re-enters the dewar (with head-cast) and the experiment can begin.
Ensure participant has a working squeeze bulb or panic button.
The intercom system must be kept on ‘listen’ throughout experiment.
Participant is monitored via video-feed throughout the experiment by _________(sign here)

Should any unexpected source of discomfort or adverse effects arise, researchers should contact the clinician on call and do their best to ensure that participant is not in pain or danger as well as debrief them. Moreover, we ask that you report any such incidents (eg migrane onset, allergy to head-cast material, claustrophobia, withdrawal from study, etc) to sofie.meyer.10@ucl.ac.uk.
See Headcast Appendix I for training. Appendix II for emergency procedures.

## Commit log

2021-02-02 added original data in STL format
    [headcoil_lpa.stl, headcoil_nas.stl, headcoil_rpa.stl]
2021-02-16 added the earflap STL parts and models to "orig"
    [earflap_part1.stl, earflap_part2.stl, earflap_part3.stl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]
2021-02-16 switched from cones to cylinders for the binoculars
2021-05-03 reorganized over subdirectories and added a startup file
    [earflap_part1.stl, earflap_part2.stl, earflap_part3.stl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]
2022-01-26 Added the interim documentation corresponding to Robert's google doc, which matches the current version of the MATLAB code.
2022-02-14 ENH - added some code and models needed for the coregistration
    [dewar_ctf.stl, dewar_mold.stl, headshape_iso2mesh.stl]
2025-05-17 split the first and second ireation of the design over two directories, update the documentation
    [dewar_ctf.stl, dewar_mold.stl, earflap_hollow.stl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]
2025-05-27 added step files
    [W0002457_02_headcore.STEP, W0002457_04_Moldcore_shape_hollow.STEP]
2025-06-03 renamed STEP files
    [W0002457_02_headcore.STEP, W0002457_04_Moldcore_shape_hollow.STEP, headcore.step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]
2025-06-03 replaced STEP files with the versions that are mutually aligned to each other - the moldcore is furthermore replaced by the small one
    [headcore.step, moldcore.step]
2025-06-03 added STL versions of the three aligned objects
    [dewar.stl, headcore.stl, moldcore.stl]
2025-06-18 added neck- and noseslab, added photo's and some small updates to the procedure
    [neckslab.stl, noseslab.stl]
